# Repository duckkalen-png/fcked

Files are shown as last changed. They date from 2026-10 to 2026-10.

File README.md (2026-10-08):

# Gimbal CAD downloads

## Complete assembly — latest concept revision

**[Download the completed 31-part gimbal assembly ZIP](Complete_Gimbal_Assembly_DOWNLOAD.zip)**. It contains the positioned AP214 STEP assembly, all separate STEP parts, a FreeCAD review file, previews, source and [joint alignment notes](COMPLETE_ASSEMBLY_README.md). [Preview the full assembly](Complete_Gimbal_Isometric_Preview.png). This revision adds fitted altitude bearings, telescope trunnion flanges and spacers, matching nominal camera/derotator interface patterns, a fitted altitude motor plate, and seated cable clips. Open the STEP as an assembly in Solid Edge and save it as `.asm` for a native Solid Edge file.

## Base with aligned fork arms and gussets

**[Download the 15-part base and fork assembly ZIP](Fork_Base_Assembly_DOWNLOAD.zip)**. It includes a positioned STEP assembly, all 15 separate STEP parts, a FreeCAD review file, a BOM, and [assembly notes](FORK_BASE_README.md). [Preview the fitted forks and gussets](Fork_Base_Preview.png). The fork feet and two gussets sit on the rotating deck, the four fork foot holes align with the deck, and the two altitude bores share one horizontal axis. Open the STEP as an assembly in Solid Edge and save it as `.asm` for a native Solid Edge file.

## Start with the base and azimuth drive

**[Download the assembled base as a ZIP](Gimbal_Base_Assembly_DOWNLOAD.zip)**. Extract `Base_Subassembly.step`; it contains eleven positioned components in a named AP214 assembly hierarchy. Open it in Solid Edge using its STEP assembly import option, then save the imported assembly as a Solid Edge `.asm` file. Solid Edge's native assembly extension is `.asm` (not `.assm`). A native Solid Edge file cannot be generated in this Linux workspace. For a FreeCAD review copy, download [Base_Subassembly.FCStd](Base_Subassembly.FCStd).

Download **[Base_Assembly_Only.zip](Base_Assembly_Only.zip)** for eleven separate STEP parts, a named base assembly STEP, a FreeCAD review assembly, and a step-by-step guide. You can also read the [assembly guide](Base_Assembly_Guide.pdf), [axial section](Base_Axial_Section.png), and [exploded view](Base_Exploded_View.png) before downloading.

## Full revised gimbal

Download **[Gimbal_CAD_v2_With_Base_Assembly.zip](Gimbal_CAD_v2_With_Base_Assembly.zip)** for all 31 STEP parts and the base subassembly. Use this revision when continuing to the fork arms; its base mounting patterns have been corrected.

The original `Gimbal_SolidEdge_STEP_Package.zip` is retained as the earlier 30-part concept. All geometry is provisional and image-derived. Bearings, motors, gear teeth, shaft/hub torque connection, fits, fasteners and structural performance need specifications before physical construction. Solid Edge can open the STEP files and save individual parts as `.par`.

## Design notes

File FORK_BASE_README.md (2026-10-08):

# Base, fork arms and gussets — concept assembly

Open `Fork_Base_Subassembly.step` as a STEP assembly in Solid Edge. It contains
15 individually named, already positioned parts: the 11-part base/azimuth
assembly plus separate left and right fork arms and separate left and right
gussets. Save the imported assembly as a native Solid Edge `.asm` if needed.
`Fork_Base_Subassembly.FCStd` is a FreeCAD review copy.

## Alignment datums (millimetres)

- Fixed base underside: Z = 0. Rotating deck top: Z = 110.
- Fork feet sit on the deck top. Fork centre planes: X = −154 and +154.
- Two foot holes per fork are centred at Y = −55 and +55. Their centres align
  with the four Ø9 deck holes at X = ±154, Y = ±55.
- Both Ø82 altitude bearing bores are coaxial along X, centred at Y = 0,
  Z = 352. The bore centre separation between the arms is 308 mm.
- Each gusset starts on the deck at Z = 110 and is trimmed to the sloping
  inner face of its fork arm. The prior 1 mm gap below the gussets is removed.

## Suggested virtual assembly order

1. Keep the existing 11-part base and azimuth assembly fixed.
2. Seat the left and right fork feet on the rotating deck and align each pair
   of foot holes with the matching deck holes.
3. Check that the altitude bores share one horizontal X axis.
4. Seat each gusset on the deck and against its corresponding fork's inner
   tapered face. The gussets are separate bodies; no weld or bolted joint has
   been specified.

All 15 imported solids are valid, and pairwise solid interference is zero in
the saved position. This verifies virtual placement, not strength or safety.
Dimensions were estimated from one reference image. Choose material, load,
joining method, fasteners, bearings and motor hardware before fabrication.

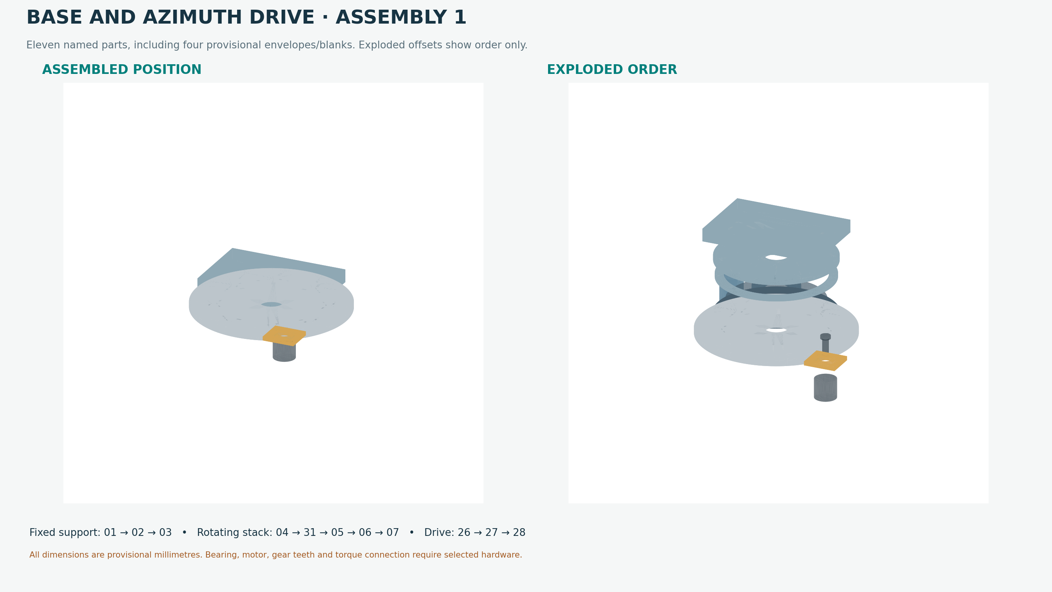
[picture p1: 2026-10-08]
Base_Exploded_View.png

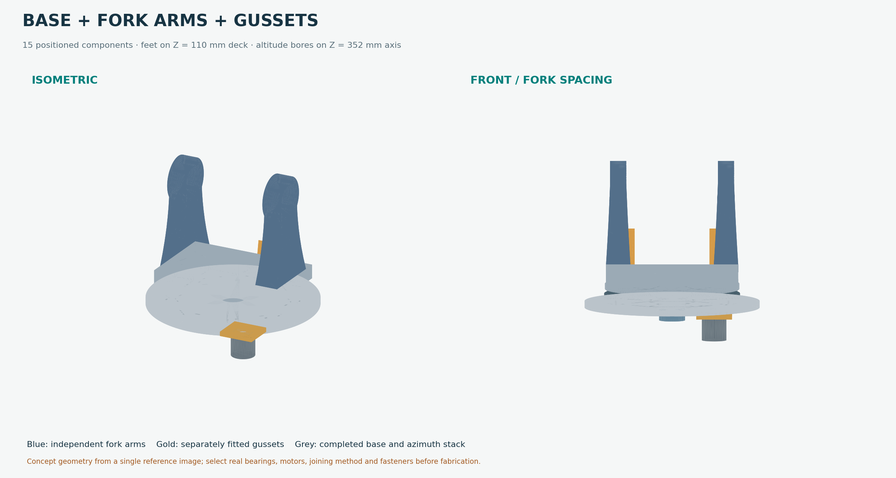
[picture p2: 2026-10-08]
Fork_Base_Preview.png

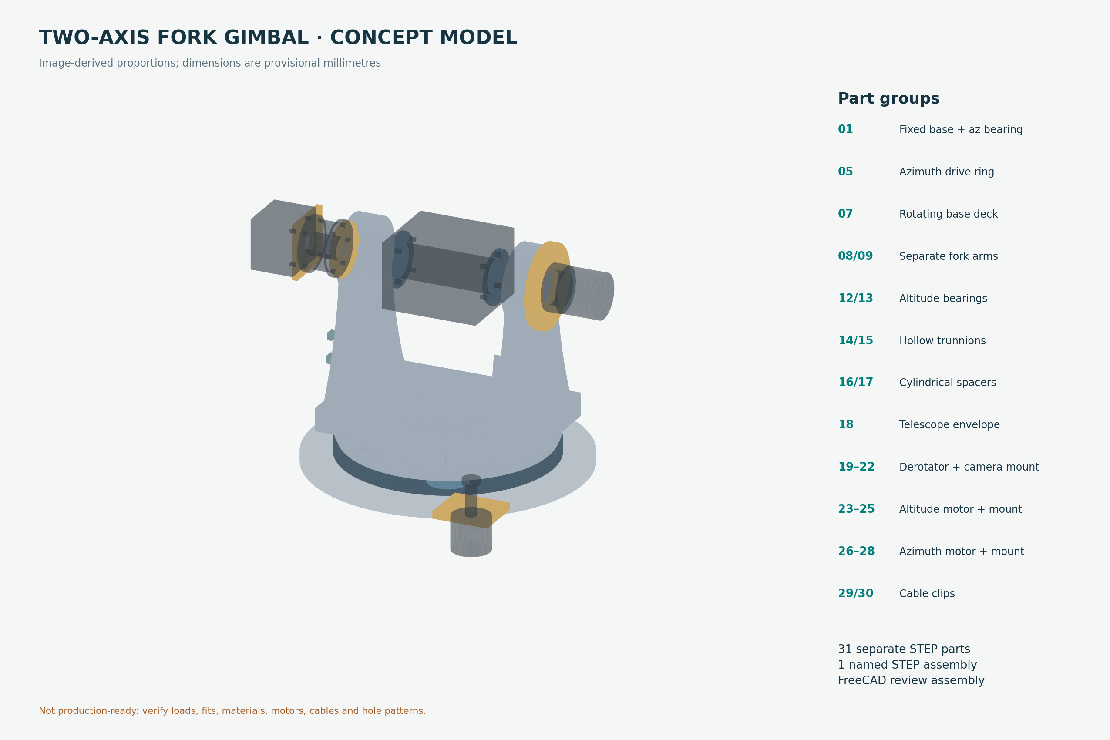
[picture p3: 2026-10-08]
Complete_Gimbal_Isometric_Preview.png

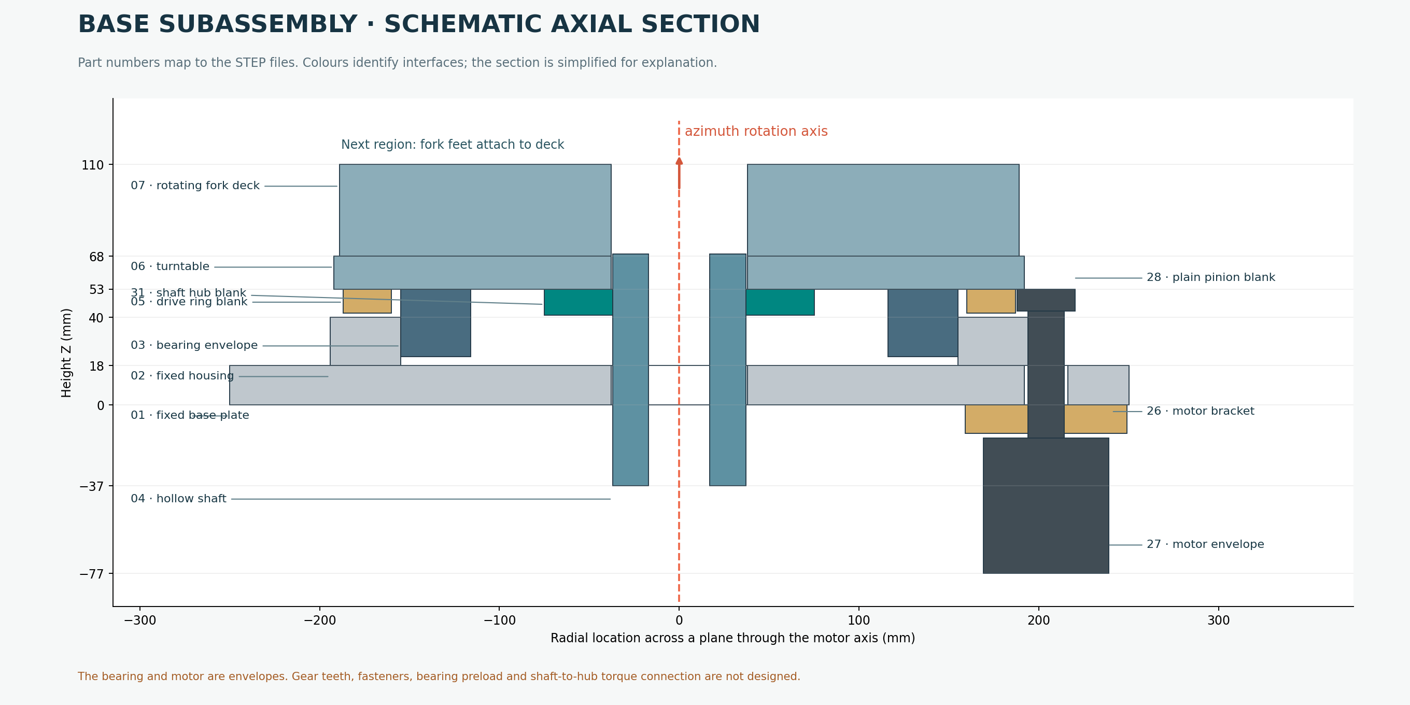
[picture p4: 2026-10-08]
Base_Axial_Section.png

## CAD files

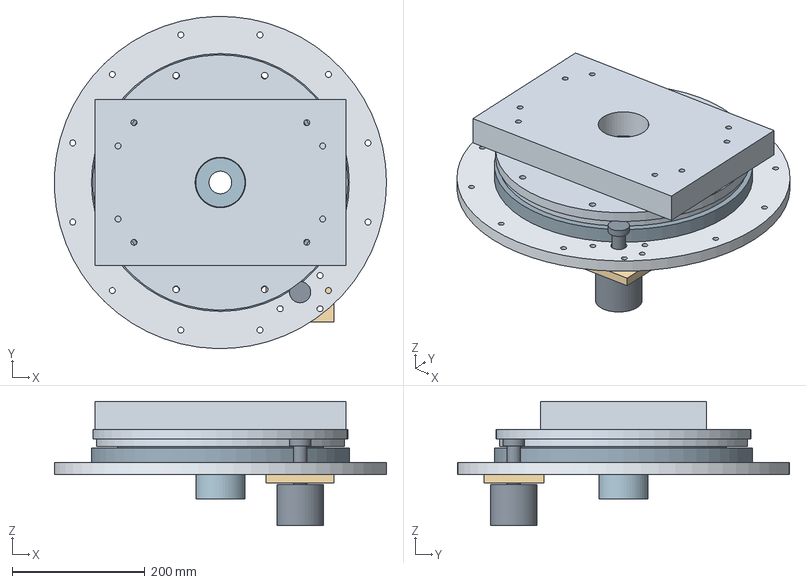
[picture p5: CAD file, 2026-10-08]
Base_Subassembly.step
499.6 x 499.8 x 187.0 mm
01_fixed_base_plate
02_az_bearing_housing
03_az_bearing_envelope
04_az_hollow_shaft
31_az_shaft_hub
05_az_drive_ring
06_az_rotating_turntable
07_rotating_base_deck
26_az_motor_mount
27_az_motor_envelope
28_az_pinion_blank

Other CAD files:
Base_Subassembly.FCStd

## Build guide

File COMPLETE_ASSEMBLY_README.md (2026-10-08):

# Complete gimbal concept assembly

`Gimbal_Assembly.step` is one named AP214 STEP assembly containing 31 separately
named, positioned components. `parts_step/` contains the corresponding
individual STEP parts. `Gimbal_Review.FCStd` is a FreeCAD review copy.

To make a native Solid Edge assembly, open `Gimbal_Assembly.step` in Solid Edge
as an assembly and save it as `.asm`. The STEP file already carries the part
positions; it does not need manual placement. A Solid Edge `.asm` cannot be
generated in this Linux workspace.

## Last-stage joint alignment (millimetres)

- Altitude rotation axis: horizontal X axis at Y = 0, Z = 352.
- Parts 12/13: nominal Ø82 outer / Ø60 inner bearing envelopes, centred in
  the fork holes at X = −154 / +154. Actual bearing type, fits and retention
  remain to be designed.
- Parts 14/15: hollow Ø60 trunnions pass through those bearing envelopes.
  Each has a four-hole inner flange on a nominal Ø80 pitch circle, seated
  against the left/right telescope side of part 18 at X = −87 / +87.
- Parts 16/17: cylindrical spacers lie between bearing inner faces
  (X = −139 / +139) and the trunnion flanges (X = −93 / +93).
- Part 18: telescope body envelope has matching blind holes on both sides.
  Its side-to-side size, loads and balance are illustrative.
- Camera side, left to right from the camera toward the telescope: part 22
  camera envelope, 21 camera interface plate, 20 derotator envelope, 19
  adapter flange, and the outer six-hole flange of part 14. Nominal hole
  patterns match at each interface, but the camera, derotator and optical
  standard are not selected.
- Motor side: part 23 altitude motor plate seats against the right fork
  and shares its four-hole pattern. Part 24 coupling meets the right
  trunnion and part 25 motor envelope. Shaft-to-coupling torque transfer,
  gearbox and motor mounting remain unengineered.
- Parts 29/30: cable clips conform to the left fork surface and align with
  its two cable mounting holes. Cable routing and bend radius are unverified.

## Checks and limits

All 31 parts and the assembly reimport as valid solids. There are no
positive-volume intersections between separate components at the saved
position. Contact and matched holes are nominal geometry, not real fits or
fastener specifications. Bearing preload, restraints, travel stops,
structural loads, clearances during motion, balance, optical path, motors,
materials and tolerances require actual component specifications before
fabrication.

The entire model remains an image-derived concept; dimensions in
`parameters.json` were assumed from the single perspective reference.

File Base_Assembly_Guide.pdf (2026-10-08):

# Base and azimuth drive: virtual fit-up


The assembled view shows the saved component positions. The exploded view separates the pieces to show their order; its offsets are illustrative.

Source: image-derived concept model. Eleven named STEP parts. Dimensions are provisional millimetres.

# How the parts stack on the azimuth axis

This section passes through the azimuth axis and the motor location. Its colours and geometry explain the interfaces; it is not a manufacturing drawing.


Read from bottom to top: fixed plate 01, bearing housing 02 and bearing envelope 03, rotating hub 31 and drive ring 05, turntable 06, then fork deck 07. The hollow shaft 04 passes through the centre.

# Parts and suggested assembly order

The new Base_Subassembly.step contains eleven separately named parts from the full gimbal. It starts with the fixed circular base and ends at the rotating rectangular deck. Base_Exploded_View.png shows the order schematically. This is the second, interface-aligned concept revision. Replace the earlier 30-part package with Gimbal_CAD_v2_With_Base_Assembly.zip when working on the base.

Coordinates: millimetres. Z is the vertical azimuth axis. The underside of the fixed base plate is Z = 0. X runs along the future altitude axis; Y is front/back. The azimuth motor is at X = 120, Y = −165 mm.

## Parts included

Stage | Part numbers | Purpose
Fixed support | 01, 02, 03 | Base plate, housing and provisional bearing annulus
Rotating stack | 04, 31, 05, 06, 07 | Hollow shaft, separate hub, drive ring, turntable and fork deck
Drive | 26, 27, 28 | Azimuth motor bracket, motor envelope and plain pinion blank

## Suggested assembly order

- 1. Orient and anchor part 01. The Ø500 × 18 base plate has twelve Ø9 foundation holes on an assumed Ø460 pitch circle. Its central Ø76 passage provides clearance for the vertical shaft envelope. Confirm the actual foundation pattern before drilling anything.
- 2. Fit part 02 to part 01. Eight Ø10 holes on an assumed Ø350 pitch circle now align between the azimuth bearing housing and the fixed plate. The housing spans Z = 18–40 mm. Fastener type, seating face and torque remain to be specified.
- 3. Place part 03 in the housing. Its Ø310 outer envelope meets the housing's nominal Ø310 seat and extends to the underside of the turntable at Z = 53 mm. This is a *space claim*, not a selected rolling-element bearing. The actual bearing determines fit, retention, preload and life.
- 4. Prepare the rotating stack. Part 04 is the hollow vertical shaft. Part 31 is a separate hub blank below the turntable (Z = 41–53). Its six Ø8 holes on Ø120 PCD match part 06. The shaft-to-hub key, clamp or other torque connection is not yet defined.
- 5. Join the drive ring and turntable. Part 05 meets the underside of part 06 at Z = 53 mm. Their eight Ø10 holes on Ø348 PCD align. The ring is a smooth blank; the eventual gear/tooth design may alter its radius and attachment.
- 6. Seat the rotating stack on the bearing. Part 06 meets the upper bearing envelope at Z = 53 mm. Check the vertical axis, the chosen bearing's axial/radial retention and clearance, and the moving parts' free rotation after actual bearing data are available.

- 7. Attach the deck. Part 07 sits on part 06 at Z = 68 mm. Four Ø9 holes at X = ±130, Y = ±90 mm align between these parts. Its top is Z = 110 mm; the next region will attach the fork feet at X = ±154, Y = ±55 mm.
- 8. Add the underside motor group. Part 26 meets the underside of the fixed plate. Its four Ø9 holes align with four fixed-plate holes. Part 27 occupies the motor volume; part 28 passes through the Ø24 drive-shaft opening. These are envelopes pending an actual gearbox and shaft interface.
- 9. Check motion and records. In the CAD model, inspect radial clearance between the fixed bearing housing and the rotating drive ring, check that hole patterns remain aligned, and record the bearing, gear, fastener and motor choices before physical assembly.

## What the fit-up establishes

- The housing-to-base, ring-to-turntable, hub-to-turntable, turntable-to-deck and motor-bracket-to-base hole centers are now matched in the exported solids.
- The bearing annulus reaches the turntable underside, and the nominal bearing/housing diameters meet.
- The ring and pinion are untoothed blanks with a deliberate gap; gear mesh has not been designed or validated.
- Individual STEP parts and Base_Subassembly.step were re-imported and checked as valid solids/assembly entities.

## Dimensions required before a physical build

Select the azimuth bearing and supply its OD, ID, width, loads and mounting instructions; the azimuth motor/gearbox and output shaft; the drive ratio and backlash requirement; the mass and center of gravity of the complete rotating assembly; foundation bolt pattern; materials, joining method, environmental and pointing requirements. These determine fits, fastener lengths and grades, preload, torque, hub/key design, stiffness and safety margins. None can be set reliably from the reference image alone.

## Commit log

2026-10-08 Add downloadable gimbal CAD concept package
2026-10-08 Add base subassembly and revised gimbal CAD
2026-10-08 Publish assembled base STEP directly
    [Base_Subassembly.FCStd, Base_Subassembly.step]
2026-10-08 Package assembled base for browser download
2026-10-08 Publish aligned fork and gusset base assembly
2026-10-08 Publish completed 31-part gimbal concept assembly
2026-10-14 Add two-piece base plate split package
2026-10-19 Add sunset peony farm track environment concept
2026-10-19 Add overcast peony and sunflower track environment
